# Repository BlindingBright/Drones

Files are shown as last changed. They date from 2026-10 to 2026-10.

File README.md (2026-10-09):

# Drones

Frames, mounts, tunes and flight-log analysis for my FPV builds. Each project lives in its own folder.

## Latest project: Lil Horny (3D whoop)

**[Lil Horny](Lil%20Horny/)** is a 65 mm 3D (reversible-motor) whoop built around a DJI O4 Lite and a
TBS Lucid AIO. It can fly upright and inverted, flipping motor direction mid-air. The folder includes
the printable mounts, the Fusion 360 design, a Betaflight tune and the AM32 ESC configs that go with it,
plus all the blackbox logs and analysis from tuning it.

The frame is based on the **Fractal 65** by Fractal Engineering, and all credit for the frame goes to them.
I tested the prints on a cut-down Fractal 65 and a cut-down Pavo Pico, and they fit both.

### Build list

| Part | Notes |
|---|---|
| Frame | Fractal 65 (or Pavo Pico), cut down |
| Flight controller / ESC | TBS Lucid AIO 1-2S (AM32). The battery mount is shaped to fit around its plugs |
| Video | DJI O4 Lite. The camera mount is made for it |
| Motors | 0802, 16000 kv |
| Props | Gemfan 123D (31 mm) |
| Battery | 2S, 200–300 mAh. Both sizes fit the same battery mount ([example 1](https://www.amazon.com/dp/B0D3F5YF9L), [example 2](https://www.amazon.com/dp/B0GXZCW923)) |

### What's in the folder

```
Lil Horny/
├── Frame Files/          Printable mounts (.obj / .stl), Fusion 360 design (.f3d + script), Lucid AIO .step
│   └── stl/              TPU standoffs (several heights)
├── Tune/
│   ├── Lil Horny 3D Master Tune.txt   Betaflight 4.5.1 CLI "diff all" — the current tune
│   ├── esc1-4_config.bin              AM32 settings for each ESC
│   └── Logs and Analysis/             Blackbox logs, plots, TUNING_NOTES.md, ESC_TEST_PLAN.md
├── README.md              Project info and build list
└── Lil Horny - Lisence Info Please Read.txt
```

### Setting it up

1. **Print the mounts** from `Frame Files/`. The standoffs are meant to be printed in TPU.
2. **ESCs (AM32 2.21):** load the `Tune/esc*_config.bin` files with [esc-configurator.com](https://esc-configurator.com)
   (props off, battery plugged in). The key settings are: bidirectional ON, 12 motor poles, timing 15°,
   startup power 100, min duty 3, motor KV 2200 (stock is fine), complementary PWM ON and running brake 10.
   Updating AM32 can reset these values (it changed timing to 22.5° on mine), so check them again after any flash.
3. **Betaflight 4.5.1:** paste `Tune/Lil Horny 3D Master Tune.txt` into the CLI and it will `save`.
   It turns on 3D mode (1496 low / 1500 neutral / 1504 high, with a deadband of 3), sets
   `motor_poles = 12` and enables bidirectional DShot.
   Before the first flight, check in the Motors tab (props off) that all four motors spin the right way in both directions.

The full pass-by-pass story of the tune — what was changed, why, and what the logs showed — is in
[`Tune/Logs and Analysis/TUNING_NOTES.md`](Lil%20Horny/Tune/Logs%20and%20Analysis/TUNING_NOTES.md).

## How to get the files

**Download everything (easiest):** click the green **Code** button at the top of this page, then **Download ZIP**.

**Clone with git:**

```bash
git clone https://github.com/BlindingBright/Drones.git
```

**Download only the Lil Horny folder** (skips the other projects):

```bash
git clone --filter=blob:none --sparse https://github.com/BlindingBright/Drones.git
cd Drones
git sparse-checkout set "Lil Horny"
```

**Single files:** open the file on GitHub and click the download (↓) button at the top right of the file view.

The project is also updated regularly on
[Google Drive](https://drive.google.com/drive/folders/10FEdRLiF6wVrJK5k8aDCwKiYdItE1z3n?usp=drive_link).

## License

Lil Horny is released under
**[Creative Commons BY-NC-SA 4.0](https://creativecommons.org/licenses/by-nc-sa/4.0/legalcode.en)**.
You're free to print, build, change and share it **for non-commercial use**, as long as you give credit and share
any changes under the same license. See `Lil Horny - Lisence Info Please Read.txt` for the full text.

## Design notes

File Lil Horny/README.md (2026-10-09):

# Lil Horny — Project Info

Lil Horny is released under [CC BY-NC-SA 4.0](https://creativecommons.org/licenses/by-nc-sa/4.0/legalcode.en). Please follow that license.

All project files are in this folder, and the project is updated regularly on
[Google Drive](https://drive.google.com/drive/folders/10FEdRLiF6wVrJK5k8aDCwKiYdItE1z3n?usp=drive_link).

The frame is based on the **Fractal 65**, created by Fractal Engineering; all credit goes to them.
In my testing I used a cut-down Pavo Pico frame and a cut-down Fractal 65. All prints work with both.

## Build List

- **TBS Lucid AIO 1-2S** (the battery mount is made for this and fits around the plugs)
- **DJI O4 Lite** (the camera mount is made for this)
- **Gemfan 123D** propellers
- **0802 16000kv** motors

Fits 200 mAh to 300 mAh 2S packs with the same battery mount:

- <https://www.amazon.com/dp/B0D3F5YF9L>
- <https://www.amazon.com/dp/B0GXZCW923>

## ESC (AM32)

- AM32 updated to 2.21
- 12 pole motor count (important with smaller motors)
- Stock KV (2200) is fine

## Betaflight

- Betaflight 4.5.1 (also set to 12 pole motor count)
- 3D settings: 1504 high, 1496 low, 1500 mid
- 3D deadband in the Receiver tab set to 3

Full CLI settings: [`Tune/Lil Horny 3D Master Tune.txt`](Tune/Lil%20Horny%203D%20Master%20Tune.txt)

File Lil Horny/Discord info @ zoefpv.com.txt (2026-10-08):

Attribution-NonCommercial-ShareAlike 4.0 International
   
CC BY-NC-SA 4.0
Legal Code
Attribution-NonCommercial-ShareAlike 4.0 InternationalExpand
Section 1 – Definitions.
Section 2 – Scope.
Section 3 – License Conditions.
Section 4 – Sui Generis Database Rights.
Section 5 – Disclaimer of Warranties and Limitation of Liability.
Section 6 – Term and Termination.
Section 7 – Other Terms and Conditions.
Section 8 – Interpretation.
Canonical URL https://creativecommons.org/licenses/by-nc-sa/4.0/
Other formats 
Plain Text
RDF/XML
See the deed
Version 4.0 • See the errata page for any corrections and the date of change

 About the license and Creative Commons
Creative Commons Corporation ("Creative Commons") is not a law firm and does not provide legal services or legal advice. Distribution of Creative Commons public licenses does not create a lawyer-client or other relationship. Creative Commons makes its licenses and related information available on an "as-is" basis. Creative Commons gives no warranties regarding its licenses, any material licensed under their terms and conditions, or any related information. Creative Commons disclaims all liability for damages resulting from their use to the fullest extent possible.

Using Creative Commons Public Licenses
Creative Commons public licenses provide a standard set of terms and conditions that creators and other rights holders may use to share original works of authorship and other material subject to copyright and certain other rights specified in the public license below. The following considerations are for informational purposes only, are not exhaustive, and do not form part of our licenses.

Considerations for licensors
Our public licenses are intended for use by those authorized to give the public permission to use material in ways otherwise restricted by copyright and certain other rights. Our licenses are irrevocable. Licensors should read and understand the terms and conditions of the license they choose before applying it. Licensors should also secure all rights necessary before applying our licenses so that the public can reuse the material as expected. Licensors should clearly mark any material not subject to the license. This includes other CC-licensed material, or material used under an exception or limitation to copyright. More considerations for licensors.

Considerations for the public
By using one of our public licenses, a licensor grants the public permission to use the licensed material under specified terms and conditions. If the licensor’s permission is not necessary for any reason–for example, because of any applicable exception or limitation to copyright–then that use is not regulated by the license. Our licenses grant only permissions under copyright and certain other rights that a licensor has authority to grant. Use of the licensed material may still be restricted for other reasons, including because others have copyright or other rights in the material. A licensor may make special requests, such as asking that all changes be marked or described. Although not required by our licenses, you are encouraged to respect those requests where reasonable. More considerations for the public.

Attribution-NonCommercial-ShareAlike 4.0 International
By exercising the Licensed Rights (defined below), You accept and agree to be bound by the terms and conditions of this Creative Commons Attribution-NonCommercial-ShareAlike 4.0 International Public License ("Public License"). To the extent this Public License may be interpreted as a contract, You are granted the Licensed Rights in consideration of Your acceptance of these terms and conditions, and the Licensor grants You such rights in consideration of benefits the Licensor receives from making the Licensed Material available under these terms and conditions.

Section 1 – Definitions.
Adapted Material means material subject to Copyright and Similar Rights that is derived from or based upon the Licensed Material and in which the Licensed Material is translated, altered, arranged, transformed, or otherwise modified in a manner requiring permission under the Copyright and Similar Rights held by the Licensor. For purposes of this Public License, where the Licensed Material is a musical work, performance, or sound recording, Adapted Material is always produced where the Licensed Material is synched in timed relation with a moving image.
Adapter's License means the license You apply to Your Copyright and Similar Rights in Your contributions to Adapted Material in accordance with the terms and conditions of this Public License.
BY-NC-SA Compatible License means a license listed at creativecommons.org/compatiblelicenses, approved by Creative Commons as essentially the equivalent of this Public License.
Copyright and Similar Rights means copyright and/or similar rights closely related to copyright including, without limitation, performance, broadcast, sound recording, and Sui Generis Database Rights, without regard to how the rights are labeled or categorized. For purposes of this Public License, the rights specified in Section 2(b)(1)-(2) are not Copyright and Similar Rights.
Effective Technological Measures means those measures that, in the absence of proper authority, may not be circumvented under laws fulfilling obligations under Article 11 of the WIPO Copyright Treaty adopted on December 20, 1996, and/or similar international agreements.
Exceptions and Limitations means fair use, fair dealing, and/or any other exception or limitation to Copyright and Similar Rights that applies to Your use of the Licensed Material.
License Elements means the license attributes listed in the name of a Creative Commons Public License. The License Elements of this Public License are Attribution, NonCommercial, and ShareAlike.
Licensed Material means the artistic or literary work, database, or other material to which the Licensor applied this Public License.
Licensed Rights means the rights granted to You subject to the terms and conditions of this Public License, which are limited to all Copyright and Similar Rights that apply to Your use of the Licensed Material and that the Licensor has authority to license.
Licensor means the individual(s) or entity(ies) granting rights under this Public License.
NonCommercial means not primarily intended for or directed towards commercial advantage or monetary compensation. For purposes of this Public License, the exchange of the Licensed Material for other material subject to Copyright and Similar Rights by digital file-sharing or similar means is NonCommercial provided there is no payment of monetary compensation in connection with the exchange.
Share means to provide material to the public by any means or process that requires permission under the Licensed Rights, such as reproduction, public display, public performance, distribution, dissemination, communication, or importation, and to make material available to the public including in ways that members of the public may access the material from a place and at a time individually chosen by them.
Sui Generis Database Rights means rights other than copyright resulting from Directive 96/9/EC of the European Parliament and of the Council of 11 March 1996 on the legal protection of databases, as amended and/or succeeded, as well as other essentially equivalent rights anywhere in the world.
You means the individual or entity exercising the Licensed Rights under this Public License. Your has a corresponding meaning.
Section 2 – Scope.
License grant.
Subject to the terms and conditions of this Public License, the Licensor hereby grants You a worldwide, royalty-free, non-sublicensable, non-exclusive, irrevocable license to exercise the Licensed Rights in the Licensed Material to:
reproduce and Share the Licensed Material, in whole or in part, for NonCommercial purposes only; and
produce, reproduce, and Share Adapted Material for NonCommercial purposes only.
Exceptions and Limitations. For the avoidance of doubt, where Exceptions and Limitations apply to Your use, this Public License does not apply, and You do not need to comply with its terms and conditions.
Term. The term of this Public License is specified in Section 6(a).
Media and formats; technical modifications allowed. The Licensor authorizes You to exercise the Licensed Rights in all media and formats whether now known or hereafter created, and to make technical modifications necessary to do so. The Licensor waives and/or agrees not to assert any right or authority to forbid You from making technical modifications necessary to exercise the Licensed Rights, including technical modifications necessary to circumvent Effective Technological Measures. For purposes of this Public License, simply making modifications authorized by this Section 2(a)(4) never produces Adapted Material.
Downstream recipients.
Offer from the Licensor – Licensed Material. Every recipient of the Licensed Material automatically receives an offer from the Licensor to exercise the Licensed Rights under the terms and conditions of this Public License.
Additional offer from the Licensor – Adapted Material. Every recipient of Adapted Material from You automatically receives an offer from the Licensor to exercise the Licensed Rights in the Adapted Material under the conditions of the Adapter’s License You apply.
No downstream restrictions. You may not offer or impose any additional or different terms or conditions on, or apply any Effective Technological Measures to, the Licensed Material if doing so restricts exercise of the Licensed Rights by any recipient of the Licensed Material.
No endorsement. Nothing in this Public License constitutes or may be construed as permission to assert or imply that You are, or that Your use of the Licensed Material is, connected with, or sponsored, endorsed, or granted official status by, the Licensor or others designated to receive attribution as provided in Section 3(a)(1)(A)(i).
Other rights.
Moral rights, such as the right of integrity, are not licensed under this Public License, nor are publicity, privacy, and/or other similar personality rights; however, to the extent possible, the Licensor waives and/or agrees not to assert any such rights held by the Licensor to the limited extent necessary to allow You to exercise the Licensed Rights, but not otherwise.
Patent and trademark rights are not licensed under this Public License.
To the extent possible, the Licensor waives any right to collect royalties from You for the exercise of the Licensed Rights, whether directly or through a collecting society under any voluntary or waivable statutory or compulsory licensing scheme. In all other cases the Licensor expressly reserves any right to collect such royalties, including when the Licensed Material is used other than for NonCommercial purposes.
Section 3 – License Conditions.
Your exercise of the Licensed Rights is expressly made subject to the following conditions.

Attribution.
If You Share the Licensed Material (including in modified form), You must:

retain the following if it is supplied by the Licensor with the Licensed Material:
identification of the creator(s) of the Licensed Material and any others designated to receive attribution, in any reasonable manner requested by the Licensor (including by pseudonym if designated);
a copyright notice;
a notice that refers to this Public License;
a notice that refers to the disclaimer of warranties;
a URI or hyperlink to the Licensed Material to the extent reasonably practicable;
indicate if You modified the Licensed Material and retain an indication of any previous modifications; and
indicate the Licensed Material is licensed under this Public License, and include the text of, or the URI or hyperlink to, this Public License.
You may satisfy the conditions in Section 3(a)(1) in any reasonable manner based on the medium, means, and context in which You Share the Licensed Material. For example, it may be reasonable to satisfy the conditions by providing a URI or hyperlink to a resource that includes the required information.
If requested by the Licensor, You must remove any of the information required by Section 3(a)(1)(A) to the extent reasonably practicable.
ShareAlike.
In addition to the conditions in Section 3(a), if You Share Adapted Material You produce, the following conditions also apply.

The Adapter’s License You apply must be a Creative Commons license with the same License Elements, this version or later, or a BY-NC-SA Compatible License.
You must include the text of, or the URI or hyperlink to, the Adapter's License You apply. You may satisfy this condition in any reasonable manner based on the medium, means, and context in which You Share Adapted Material.
You may not offer or impose any additional or different terms or conditions on, or apply any Effective Technological Measures to, Adapted Material that restrict exercise of the rights granted under the Adapter's License You apply.
Section 4 – Sui Generis Database Rights.
Where the Licensed Rights include Sui Generis Database Rights that apply to Your use of the Licensed Material:

for the avoidance of doubt, Section 2(a)(1) grants You the right to extract, reuse, reproduce, and Share all or a substantial portion of the contents of the database for NonCommercial purposes only;
if You include all or a substantial portion of the database contents in a database in which You have Sui Generis Database Rights, then the database in which You have Sui Generis Database Rights (but not its individual contents) is Adapted Material, including for purposes of Section 3(b); and
You must comply with the conditions in Section 3(a) if You Share all or a substantial portion of the contents of the database.
For the avoidance of doubt, this Section 4 supplements and does not replace Your obligations under this Public License where the Licensed Rights include other Copyright and Similar Rights.

Section 5 – Disclaimer of Warranties and Limitation of Liability.
Unless otherwise separately undertaken by the Licensor, to the extent possible, the Licensor offers the Licensed Material as-is and as-available, and makes no representations or warranties of any kind concerning the Licensed Material, whether express, implied, statutory, or other. This includes, without limitation, warranties of title, merchantability, fitness for a particular purpose, non-infringement, absence of latent or other defects, accuracy, or the presence or absence of errors, whether or not known or discoverable. Where disclaimers of warranties are not allowed in full or in part, this disclaimer may not apply to You.
To the extent possible, in no event will the Licensor be liable to You on any legal theory (including, without limitation, negligence) or otherwise for any direct, special, indirect, incidental, consequential, punitive, exemplary, or other losses, costs, expenses, or damages arising out of this Public License or use of the Licensed Material, even if the Licensor has been advised of the possibility of such losses, costs, expenses, or damages. Where a limitation of liability is not allowed in full or in part, this limitation may not apply to You.
The disclaimer of warranties and limitation of liability provided above shall be interpreted in a manner that, to the extent possible, most closely approximates an absolute disclaimer and waiver of all liability.
Section 6 – Term and Termination.
This Public License applies for the term of the Copyright and Similar Rights licensed here. However, if You fail to comply with this Public License, then Your rights under this Public License terminate automatically.
Where Your right to use the Licensed Material has terminated under Section 6(a), it reinstates:

automatically as of the date the violation is cured, provided it is cured within 30 days of Your discovery of the violation; or
upon express reinstatement by the Licensor.
For the avoidance of doubt, this Section 6(b) does not affect any right the Licensor may have to seek remedies for Your violations of this Public License.

For the avoidance of doubt, the Licensor may also offer the Licensed Material under separate terms or conditions or stop distributing the Licensed Material at any time; however, doing so will not terminate this Public License.
Sections 1, 5, 6, 7, and 8 survive termination of this Public License.
Section 7 – Other Terms and Conditions.
The Licensor shall not be bound by any additional or different terms or conditions communicated by You unless expressly agreed.
Any arrangements, understandings, or agreements regarding the Licensed Material not stated herein are separate from and independent of the terms and conditions of this Public License.
Section 8 – Interpretation.
For the avoidance of doubt, this Public License does not, and shall not be interpreted to, reduce, limit, restrict, or impose conditions on any use of the Licensed Material that could lawfully be made without permission under this Public License.
To the extent possible, if any provision of this Public License is deemed unenforceable, it shall be automatically reformed to the minimum extent necessary to make it enforceable. If the provision cannot be reformed, it shall be severed from this Public License without affecting the enforceability of the remaining terms and conditions.
No term or condition of this Public License will be waived and no failure to comply consented to unless expressly agreed to by the Licensor.
Nothing in this Public License constitutes or may be interpreted as a limitation upon, or waiver of, any privileges and immunities that apply to the Licensor or You, including from the legal processes of any jurisdiction or authority.

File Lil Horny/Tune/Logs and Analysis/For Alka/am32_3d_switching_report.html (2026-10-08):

AM32 2.21 · 3D direction-switch test · Oct 2026

# Lucid AIO 3D Switching Tests

Min duty and KV slider tests on a 3D whoop, following your suggested plan: default, then min duty 3, then KV halved, then min duty 4 with KV ~2200 (flown at 2100). Plus the earlier logs comparing factory firmware, 22.5° timing and startup power 120.

Craft TBS Lucid AIO (AT32F435 FC + AM32 ESC) · 0802 16000kv, 12-pole · Gemfan 31mm prototype 3D props · 2S 300mAh · DJI O4 Lite · ~30 g
Betaflight 4.5.1 · 8k/8k · feature 3D · DShot600 bidir · dshot_idle_value 400 (4%) · thrust_linear 20 · blackbox 2 kHz
AM32 constant bidirectional, comp PWM, variable PWM, stuck rotor ON · sine startup OFF · timing 15° · startup 100 · poles 12 · running brake 10

## Summary

- Min duty 4 + KV 2100 is the clear winner: median switch 153 → 126 ms (−18%), now faster than factory 2.03 (136 ms). All four motors land within 5 ms of each other (125–130 ms).
- It's also the smoothest: low-rpm eRPM ripple halved (3.3k → 1.7k), motor spread 70 → 38 ms, slow switches 33% → 7%.
- The rough 30–60k eRPM window finally moved: with min duty 3 / KV 5100 it sat at ~40–110 ms after every switch. With min duty 4 / KV 2100 the motor dips to ~20k at ~60 ms and is climbing by ~85 ms.
- Min duty 3 alone smoothed things; KV 5100 alone added speed but brought ripple back; the low KV + min duty 4 combination got both.
- Final: min duty back to 3 at KV 2100 (E) switches exactly as fast as D (126 ms median), a bit more consistently (p90 148 ms, spread 34 ms), with less pitch overshoot. This is the setting we're keeping.

## Min duty / KV test (A → E)

Same Betaflight config for every run; B–D on the same day with the same props. Times are from the moment Betaflight flips direction until each motor reaches 100k eRPM in the new direction; medians over clean reversals (no second flip within 450 ms). Impacts trimmed out.

Config | Reversals | Switch median | Switch p90 | Restart phase (min → 100k) | Slow >200 ms | Motor spread | Low-rpm ripple | Attitude kick med / p90
A · default (min duty 0.5, KV 10220) | 52 | 153 ms | 183 ms | 45 ms | 17 (33%) | 70 ms | 3.3k | 60 / 136 °/s
B · min duty 3 | 23 | 147 ms | 172 ms | 42 ms | 1 (4%) | 49 ms | 1.8k | 85 / 173 °/s
C · min duty 3 + KV 5100 | 28 | 142 ms | 172 ms | 39 ms | 1 (4%) | 45 ms | 3.5k | 68 / 172 °/s
D · min duty 4 + KV 2100 | 30 | 126 ms | 154 ms | 37 ms | 2 (7%) | 38 ms | 1.7k | 82 / 149 °/s
E · min duty 3 + KV 2100 (kept) | 28 | 126 ms | 148 ms | 36 ms | 1 (4%) | 34 ms | 1.8k | 84 / 185 °/s

Per-motor median switch (BF m0 / m1 / m2 / m3) | m0 | m1 | m2 | m3
A · default | 152 | 147 | 156 | 155
B · min duty 3 | 143 | 149 | 146 | 154
C · min duty 3 + KV 5100 | 139 | 135 | 139 | 149
D · min duty 4 + KV 2100 | 125 | 128 | 126 | 130
E · min duty 3 + KV 2100 | 118 | 128 | 123 | 129

Low-rpm ripple = RMS of 20–200 Hz eRPM ripple while a motor runs between 5k and 150k eRPM, away from reversals. A pools two days of default flying (3 packs). Attitude kick = peak roll/pitch tracking error in the 300 ms after a switch.

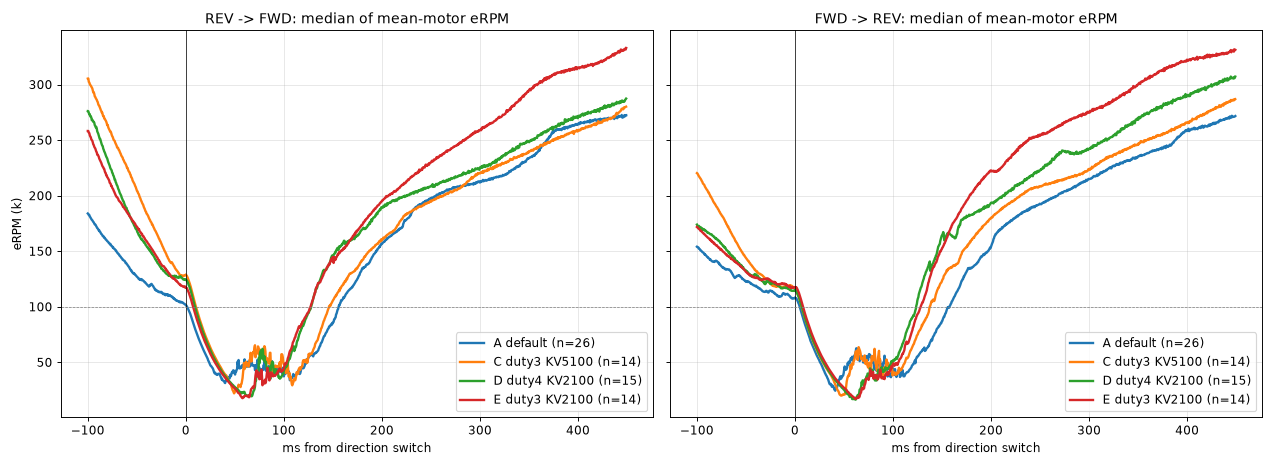
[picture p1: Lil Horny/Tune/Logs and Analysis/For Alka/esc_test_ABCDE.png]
Median mean-motor eRPM through reversals for configs A, C, D and E, both directions


Median eRPM (mean of 4 motors) aligned on the direction switch. A and C sit in a noisy 30–60k section from ~40–110 ms. Both KV 2100 runs (D green, E red) dip cleaner to ~20k around 60 ms and reach 100k ~15–20 ms ahead of C in both directions. D and E overlap through the switch itself. B is left off for readability.

## Earlier logs: firmware and other settings

Log | Reversals | Switch median | Switch p90 | Stop phase | Motor spread
Factory AM32 (2.03), timing 15° | 24 | 136 ms | 169 ms | 68 ms | 37 ms
2.21, timing 22.5° (reset by the update) | 10 | 140 ms | 168 ms | 88 ms | 49 ms
2.21, timing 15° | 20 | 146 ms | 175 ms | 91 ms | 37 ms
2.21, startup power 120 | 11 | 144 ms | 162 ms | 98 ms | 56 ms
2.21, startup power 100 (default) | 16 | 148 ms | 177 ms | 97 ms | 62 ms

Stop phase = switch → eRPM minimum. On 2.21 the stop phase is ~30 ms longer than on factory firmware; the restart phase is actually a little shorter on 2.21. Factory log caveats: Betaflight idle was 2.8% and the Betaflight tune was untuned (first flight).

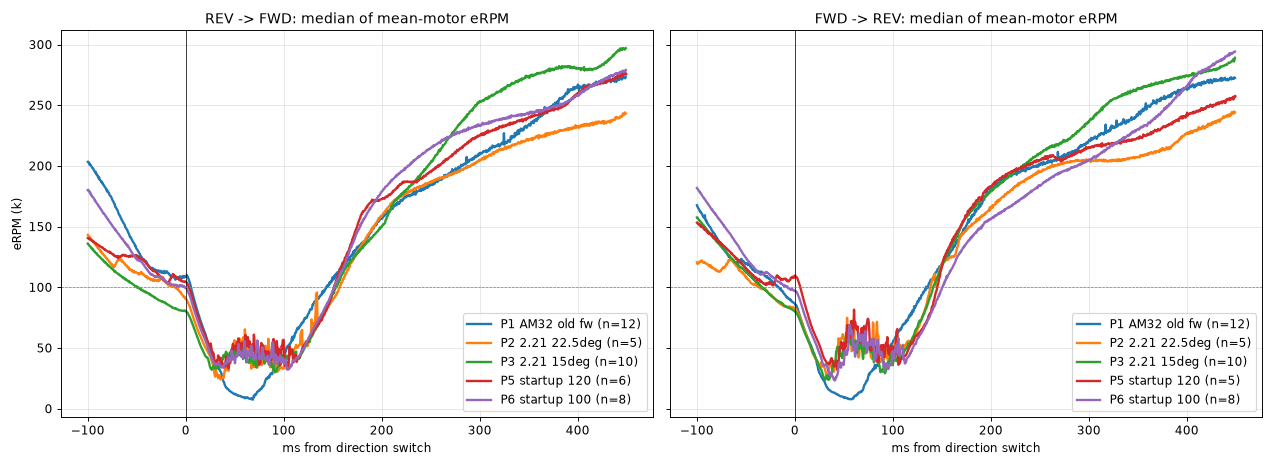
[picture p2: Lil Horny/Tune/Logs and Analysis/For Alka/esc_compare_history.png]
Median mean-motor eRPM through reversals for factory firmware and several 2.21 settings


Factory 2.03 (blue) falls through to ~10k eRPM at ~60 ms and climbs straight out. Every 2.21 setting sits in the rough 30–60k section first.

## Other observations

Min duty adds on top of the Betaflight idle. At the same dshot_idle_value (4%), idle speed rose from roughly 70–79k (A) to 87–93k (B) and 85–101k (D) eRPM. Center stick floats a bit more as a result.

KV 5100 alone cost smoothness; KV 2100 + min duty 4 didn't. C's ripple went back to default levels, D's is the lowest of any run.

Flight side effect in D: pitch overshoot rose a little (step peak 1.22 → 1.37). Back at min duty 3 (E) it returned to 1.22, and inverted motor jitter dropped (19 → 17).

D vs E is close enough that the pilot couldn't pick one by feel; the logs agree. Same switch speed and smoothness, E slightly more consistent.

No desyncs or failed restarts in A–E.

Failed restart · 2.21 at 22.5° timing

### Motor never restarted after a reversal

Right after the AM32 update (which silently changed timing 15° → 22.5°), BF motor 0 (ESC M1) went to 0 eRPM after a REV → FWD switch at ~37.1 s and stayed there for 0.75 s while Betaflight commanded 2047, then the quad crashed. Stuck rotor protection was ON. The other three motors restarted normally. No repeat since going back to 15°.

File 02, log 4 of 5.

## Questions

1. The 30–60k eRPM section shrank only at KV 2100. Is that the low-rpm throttle limit releasing, and is there more to get by going lower than 2100 or higher on min duty, or does desync risk climb fast from here?
2. What changed in 3D reversal handling between 2.03 and 2.21? Factory firmware stopped the motor ~30 ms faster at default settings.
3. Worth trying lower startup power with min duty 4 for smoothness, or leave startup at 100?
4. You mentioned a possible 3D fix for desyncs. Would the failed restart above be relevant?

## Log files

File | What to look at
01_AM32-factory-2.03_… | Factory reference. AM32 still had poles set to 14.
02_AM32-2.21_timing22.5-…_STALL-in-log4 | 5 logs. Log 4 = failed restart at ~37.1 s. Log 1 end = prop came off (not ESC). Log 5 = clean flight.
03_…_startup120_… | Tree hit at 55.8 s.
04_…_DEFAULT-A1 | Log 4 is the flight (106 s, clean).
05_…_DEFAULT-A2 | 2 packs. Impact at 70.0 s in log 1; log 2 truncated (flash full).
06_…_minduty3_kv10220_TEST-B | Log 3 is the flight; impact at 79 s.
07_…_minduty3_kv5100_TEST-C | Crash at 88.6 s.
08_…_minduty4_kv2100_TEST-D | Clean 86 s flight, no impacts.
09_…_minduty3_kv2100_TEST-E | Clean 94 s flight, no impacts. Final setting.

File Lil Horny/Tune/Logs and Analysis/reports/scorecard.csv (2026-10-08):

label | duration_s | motor_poles | reversals | rev_spinup_ms_med | rev_motor_spread_ms_med | rev_peak_err_med | rev_peak_err_p90 | steady_err_rms_roll | steady_err_rms_pitch | steady_err_rms_yaw | gyro_unfilt_400_1000_db_roll | gyro_filt_80_400_db_roll | dterm_rms_roll | dterm_rms_pitch | step_peak_roll | step_settle_roll | step_peak_pitch | step_settle_pitch | step_peak_yaw | step_settle_yaw
Pass 1 baseline | 86.2 | 14 | 24 | 110.9 | 51.5 | 48.0 | 106.0 | 14.9 | 13.9 | 9.2 | -5.8 | -16.9 | 20.4 | 15.7 | 1.14 | 0.88 | 1.34 | 1.0 | 0.91 | 0.82
Pass 2 log5 (good flight) | 54.2 | 12 | 10 | 113.6 | 77.1 | 72.0 | 291.0 | 9.0 | 6.3 | 2.9 | -4.7 | -18.2 | 16.3 | 13.7 | 1.13 | 0.88 | 1.38 | 0.91 | 0.97 | 0.87
Pass 3 | 93.8 | 12 | 20 | 115.2 | 51.8 | 54.0 | 135.0 | 7.7 | 6.6 | 3.0 | -4.4 | -22.3 | 14.5 | 11.3 | 1.08 | 0.87 | 1.22 | 0.95 | 0.86 | 0.78
Pass 4 (crash trimmed) | 47.6 | 12 | 9 | 112.0 | 46.7 | 70.0 | 129.0 | 7.7 | 5.5 | 2.8 | -5.2 | -17.3 | 22.2 | 17.4 | 1.12 | 0.93 | 1.55 | 1.09 | 0.85 | 0.78
Pass 5 (tree trimmed) | 55.5 | 12 | 12 | 121.6 | 70.0 | 71.0 | 337.0 | 6.3 | 6.5 | 2.6 | -4.7 | -14.5 | 19.3 | 17.4 | 1.03 | 0.88 | 1.35 | 0.92 | 0.92 | 0.83
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

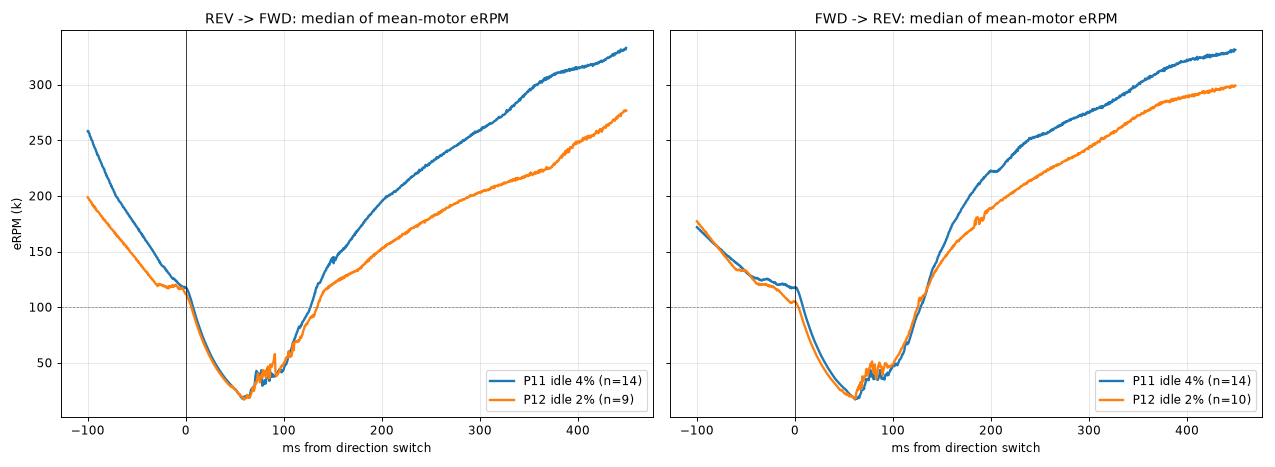
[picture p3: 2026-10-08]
Lil Horny/Tune/Logs and Analysis/reports/esc_idle_E_vs_12.png

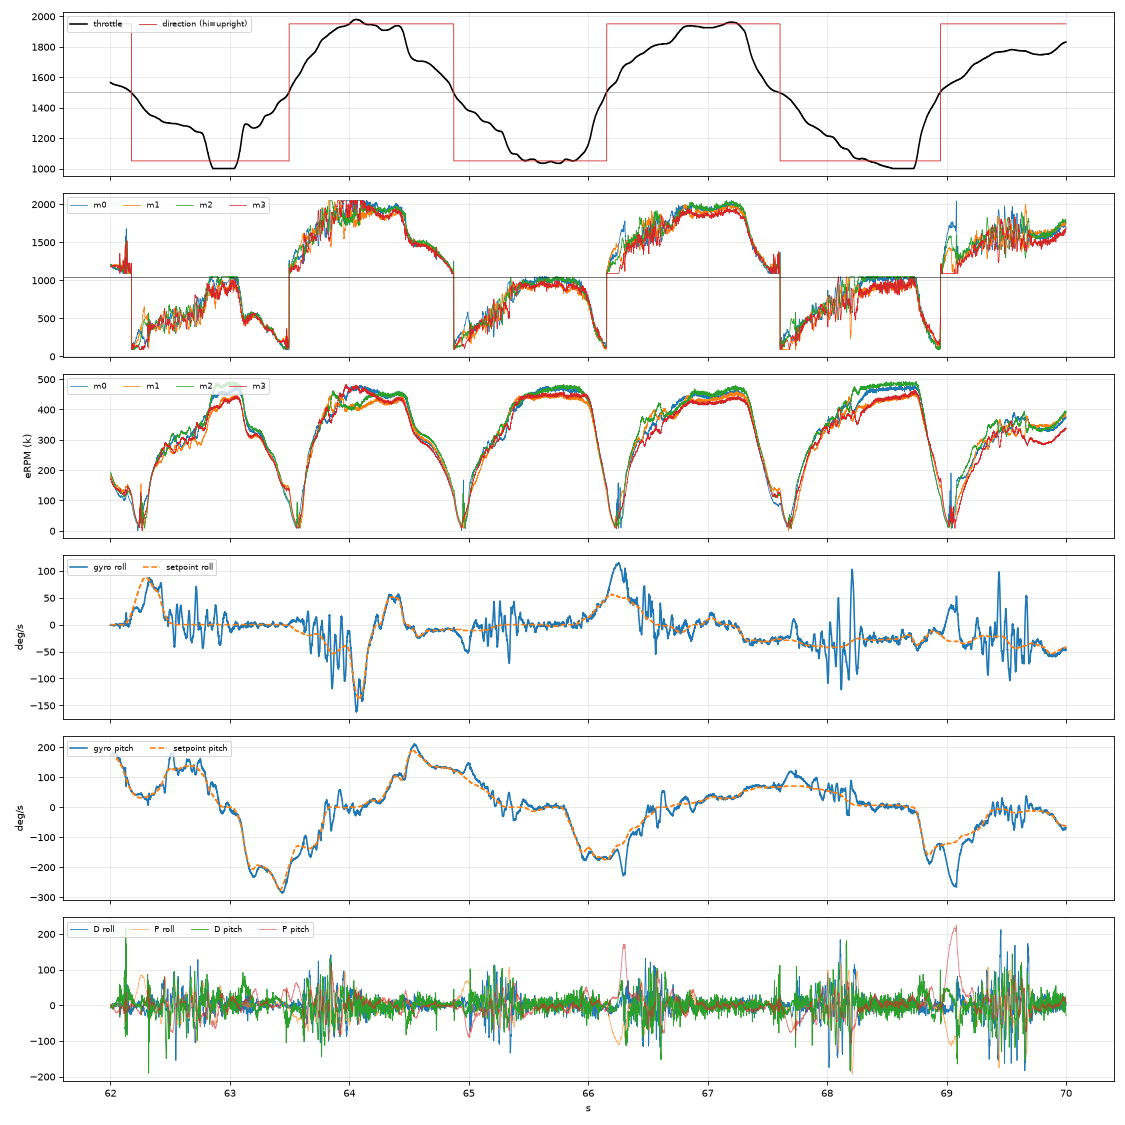
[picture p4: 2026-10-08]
Lil Horny/Tune/Logs and Analysis/reports/Pass_11_ticktock.png

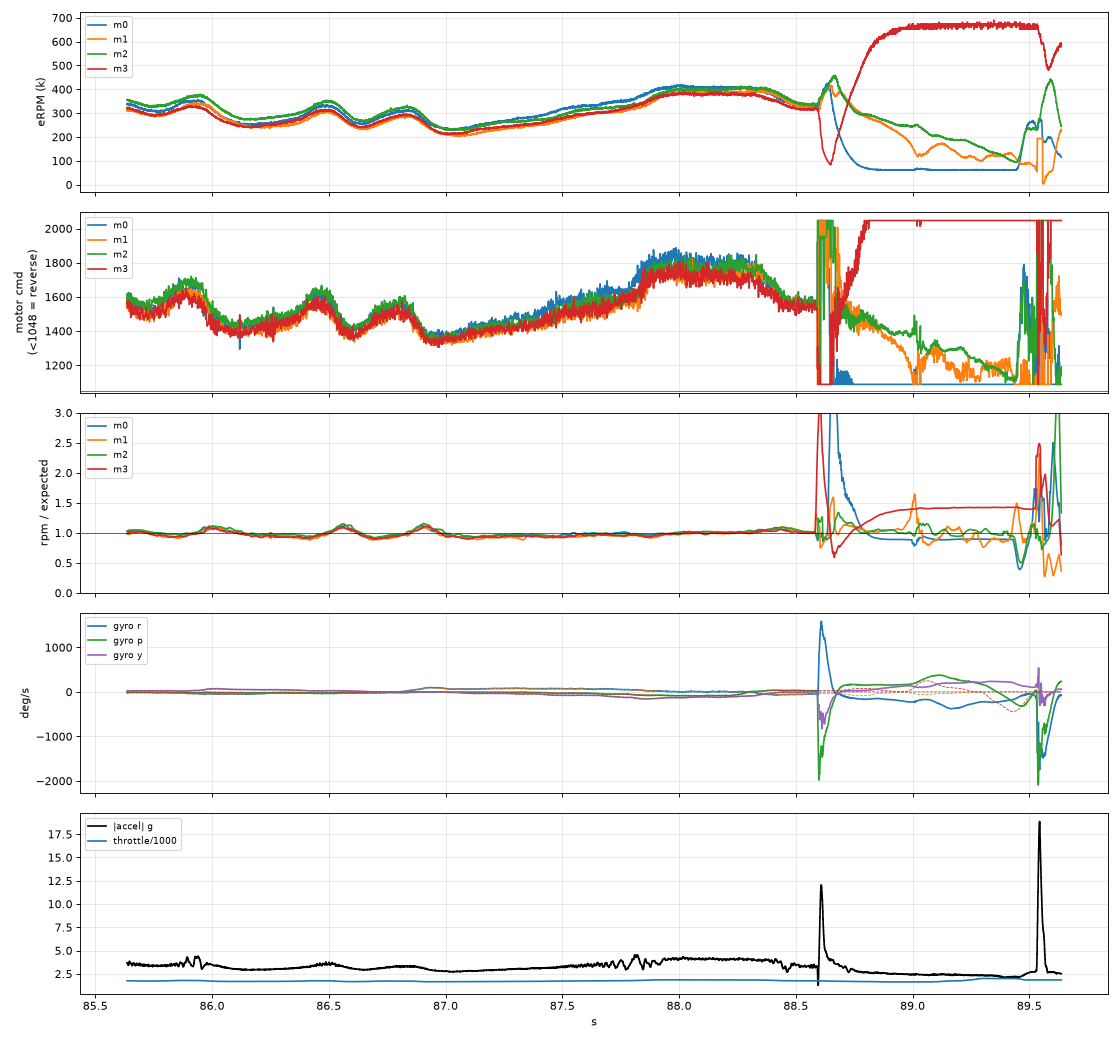
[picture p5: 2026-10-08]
Lil Horny/Tune/Logs and Analysis/reports/Pass_9_crash.png

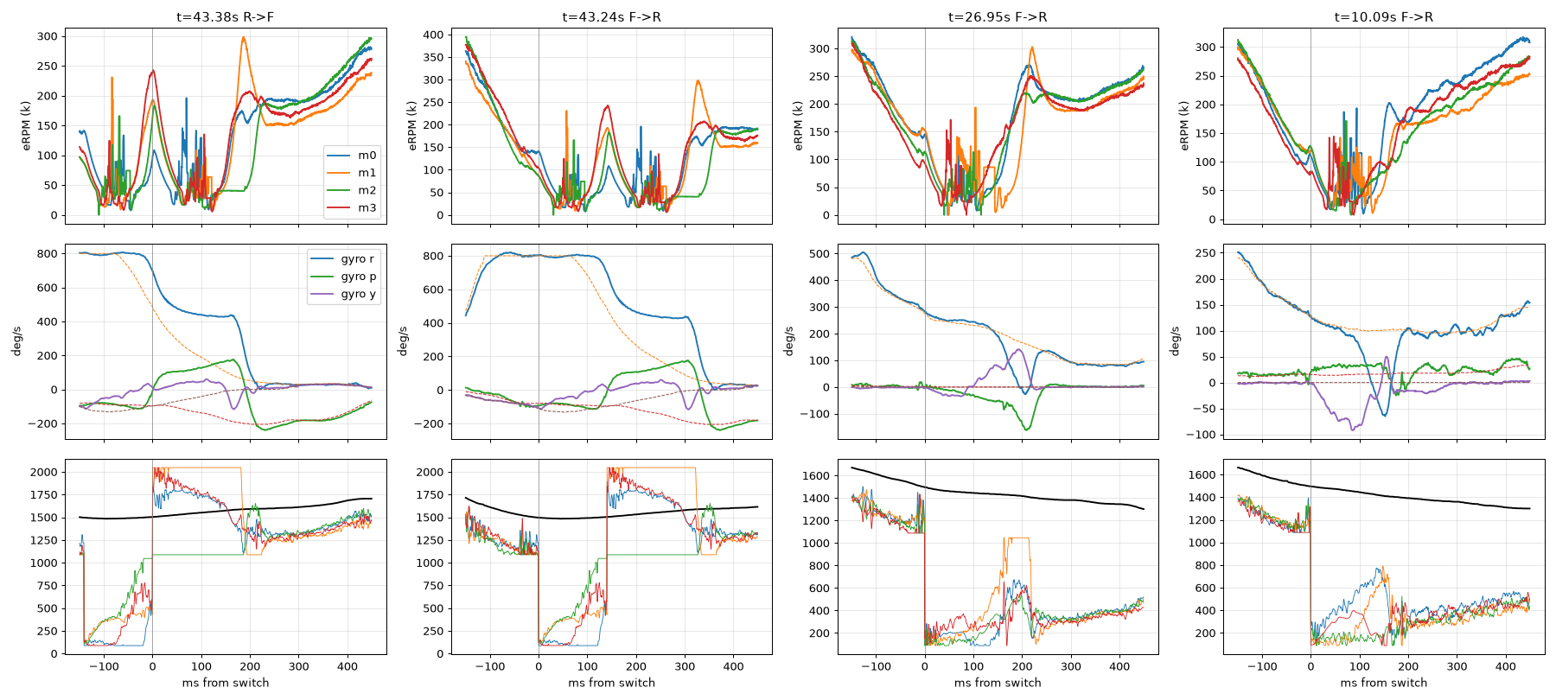
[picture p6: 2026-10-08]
Lil Horny/Tune/Logs and Analysis/reports/Pass_5__tree_trimmed__worst_reversals.png

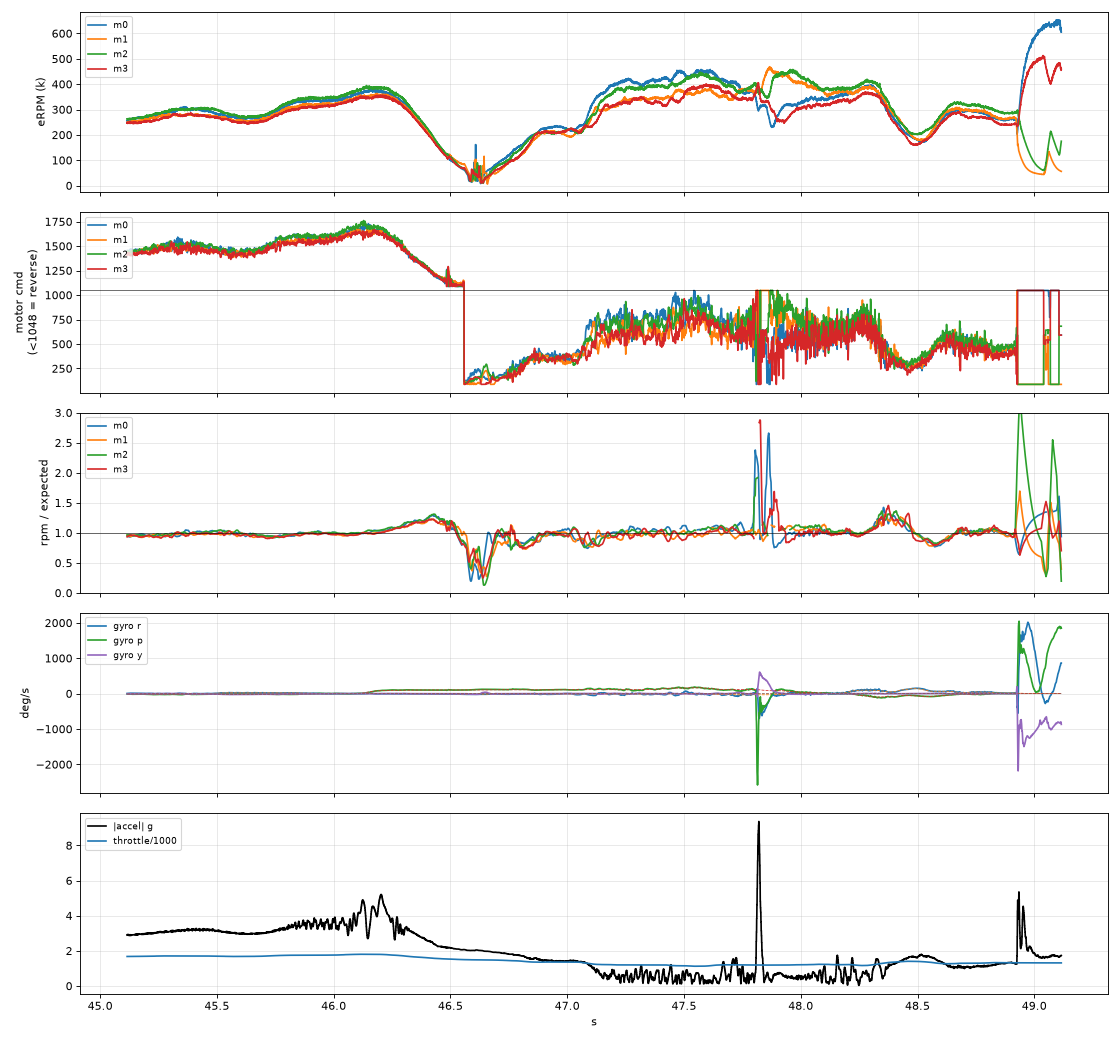
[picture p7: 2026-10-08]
Lil Horny/Tune/Logs and Analysis/reports/Pass_4_crash.png

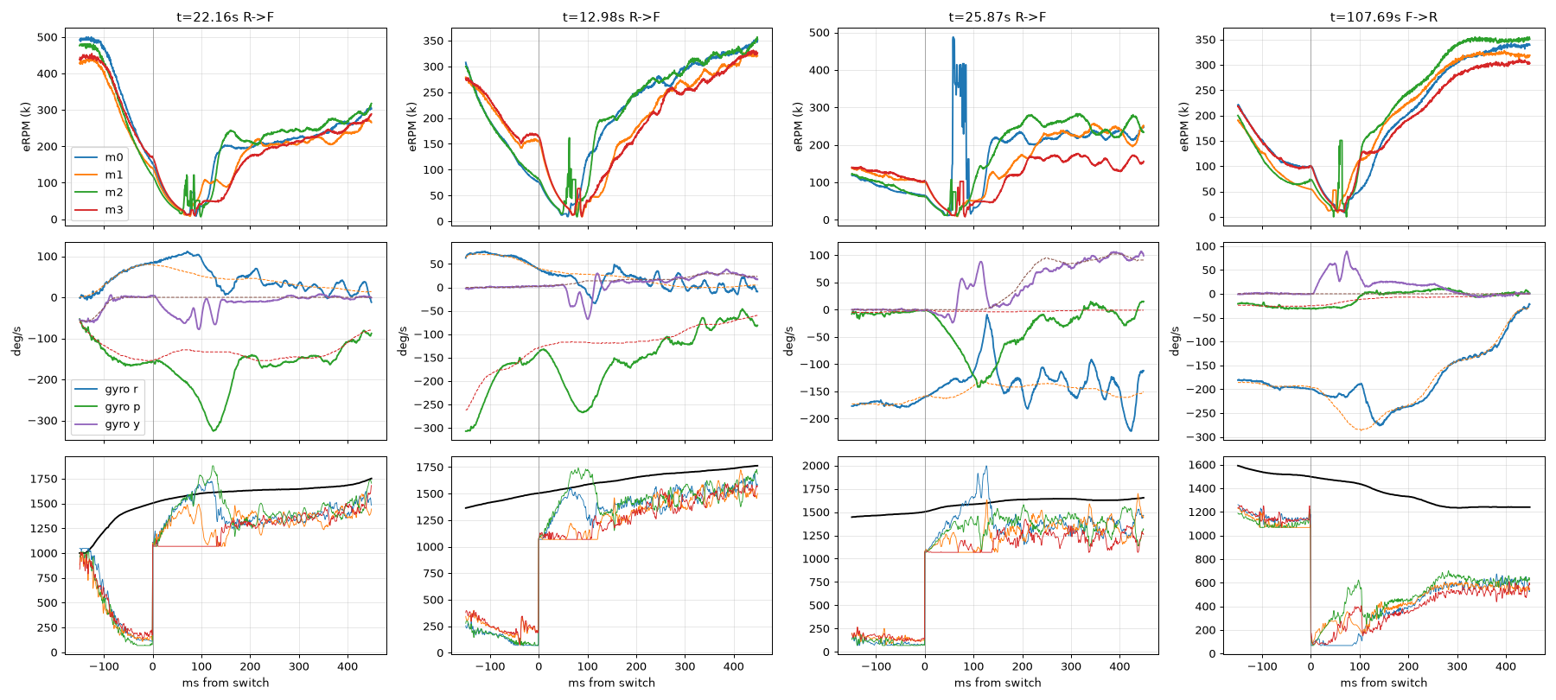
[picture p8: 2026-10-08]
Lil Horny/Tune/Logs and Analysis/reports/Pass_14_worst_reversals.png

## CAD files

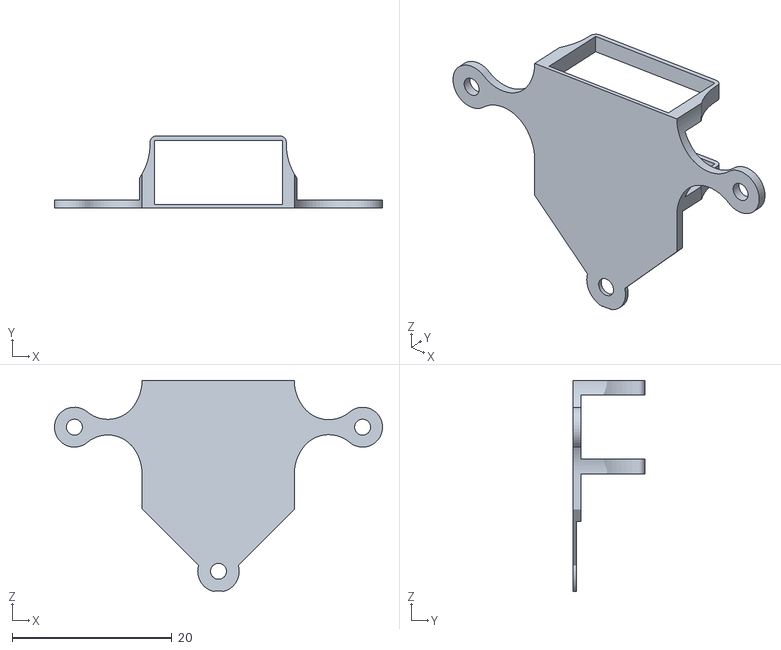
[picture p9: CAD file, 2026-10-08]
Lil Horny/Frame Files/Battery Mount.obj
41.0 x 9.00 x 26.4

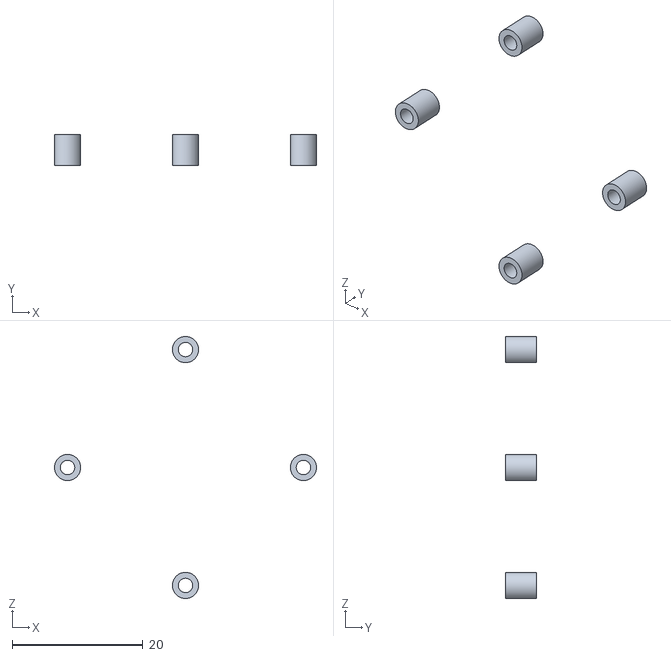
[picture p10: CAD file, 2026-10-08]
Lil Horny/Frame Files/stl/standoffs_TOP_O4-to-Lucid_4.7mm_x4.stl
40.1 x 4.70 x 40.1

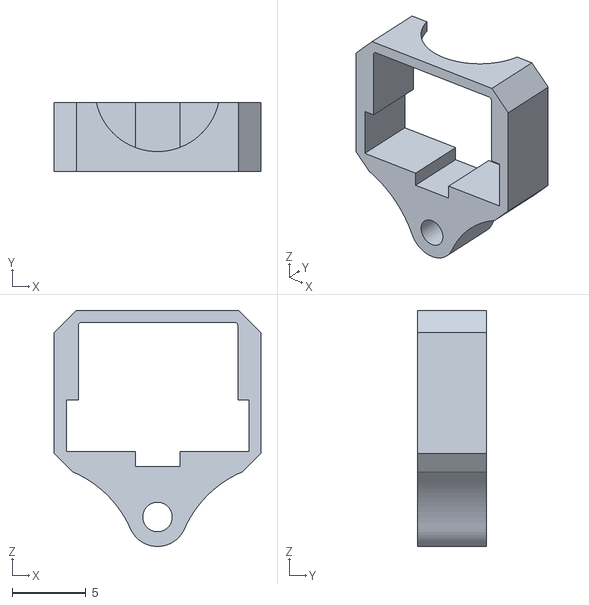
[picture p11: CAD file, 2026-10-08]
Lil Horny/Frame Files/Camera Mount.obj
14.0 x 4.70 x 16.0

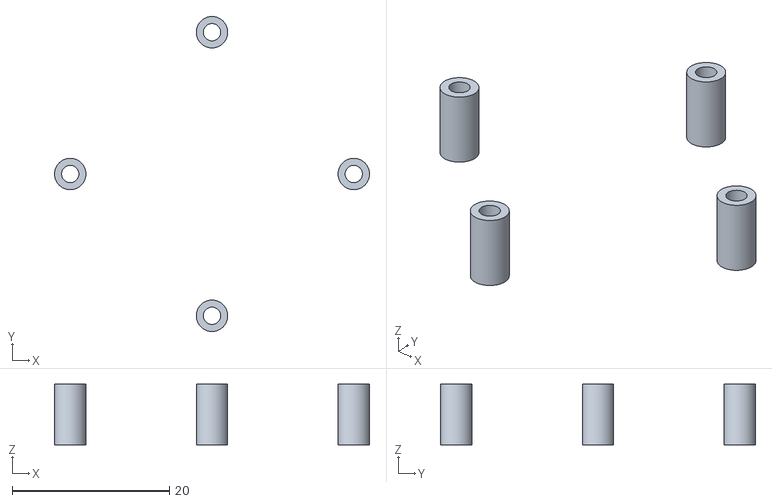
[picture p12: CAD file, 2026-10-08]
Lil Horny/Frame Files/stl/standoffs_TOP_O4-to-Lucid_7.7mm_x4.stl
40.1 x 40.1 x 7.70

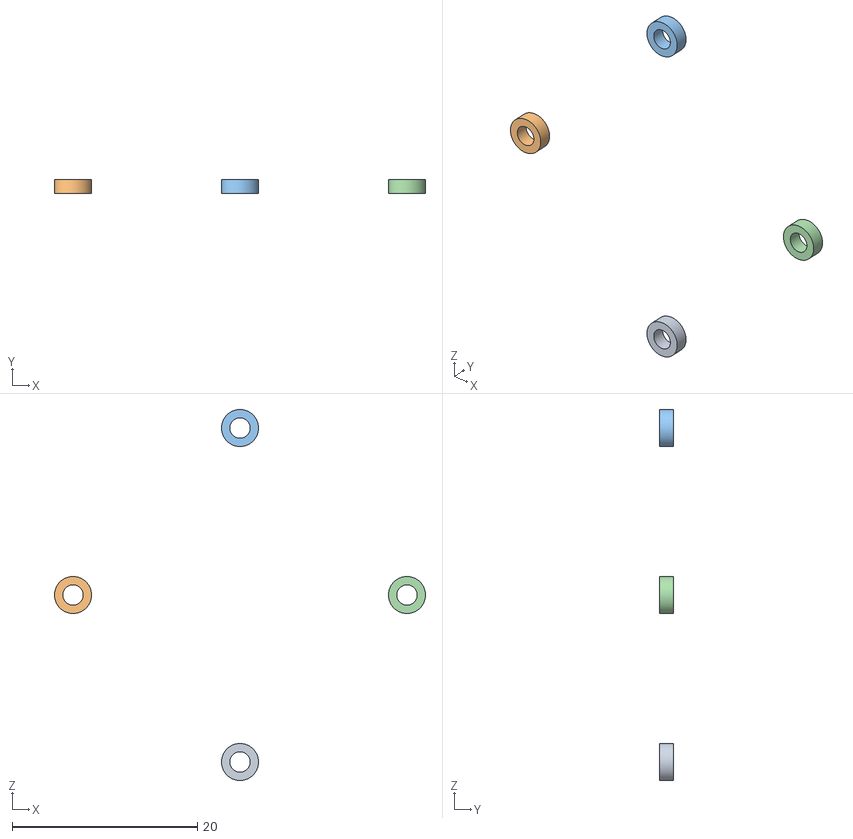
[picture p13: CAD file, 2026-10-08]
Lil Horny/Frame Files/Standoffs BOTTOM plate-O4 1.5mm x4 (TPU).obj
40.1 x 1.50 x 40.1
Standoff 1
Standoff 2
Standoff 3
Standoff 4

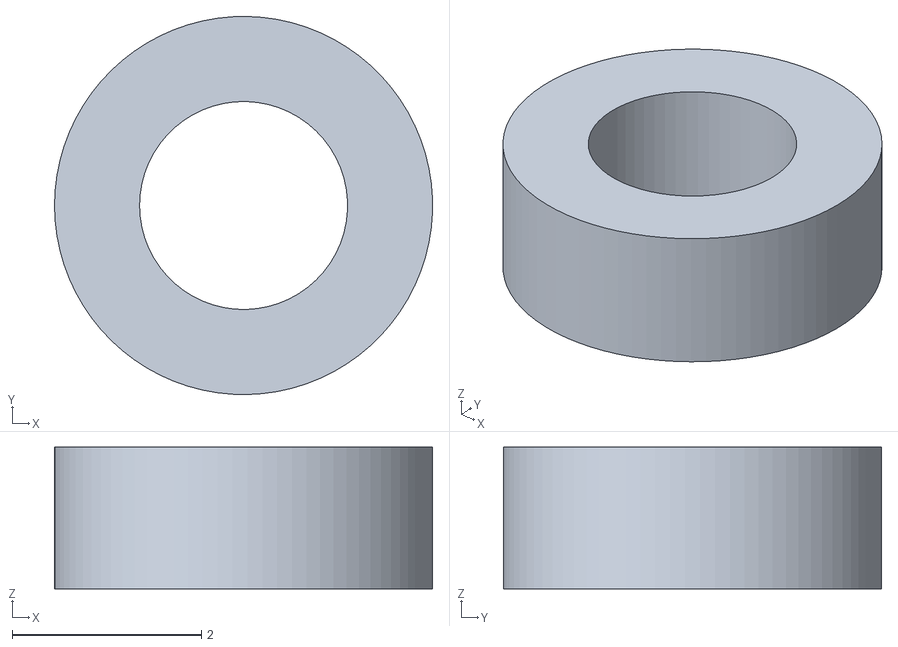
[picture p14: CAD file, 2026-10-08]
Lil Horny/Frame Files/stl/standoff_lower_plate-to-O4_1.5mm_x4.stl
4.00 x 4.00 x 1.50

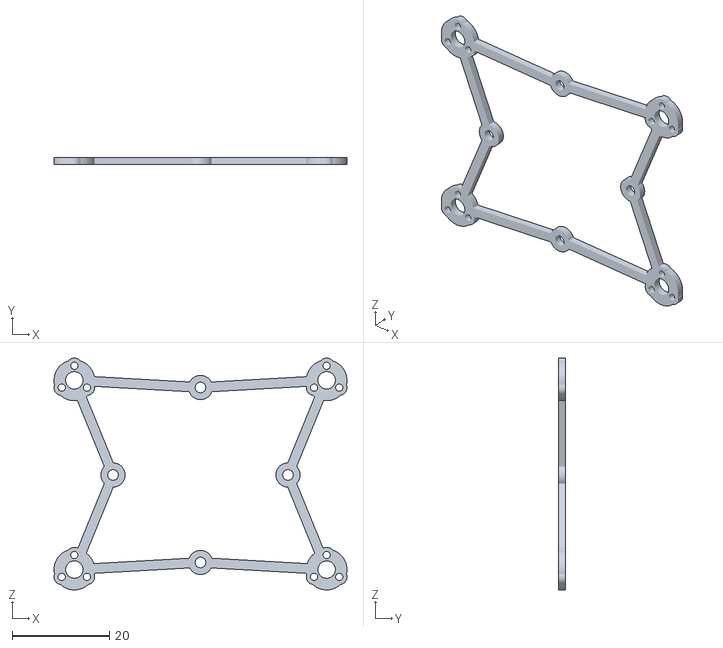
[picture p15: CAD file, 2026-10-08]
Lil Horny/Frame Files/Frame - Fractal 65 Lite (streamlined).obj
60.4 x 1.50 x 47.8

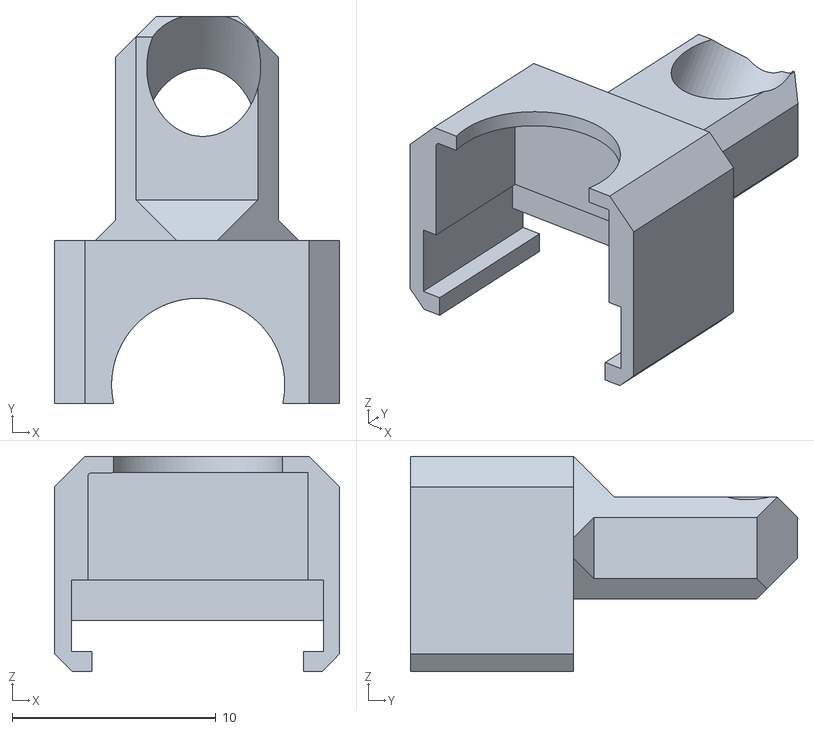
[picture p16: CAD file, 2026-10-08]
Lil Horny/Frame Files/Antenna Mount.obj
14.0 x 19.0 x 10.6

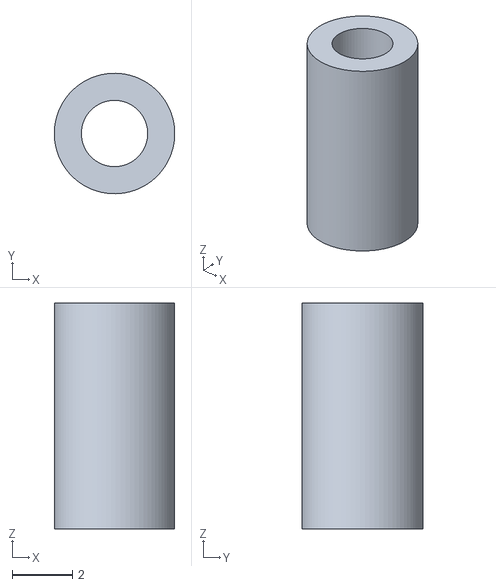
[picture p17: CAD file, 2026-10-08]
Lil Horny/Frame Files/stl/standoff_upper_O4-to-Lucid_7.5mm_x4.stl
4.00 x 4.00 x 7.50

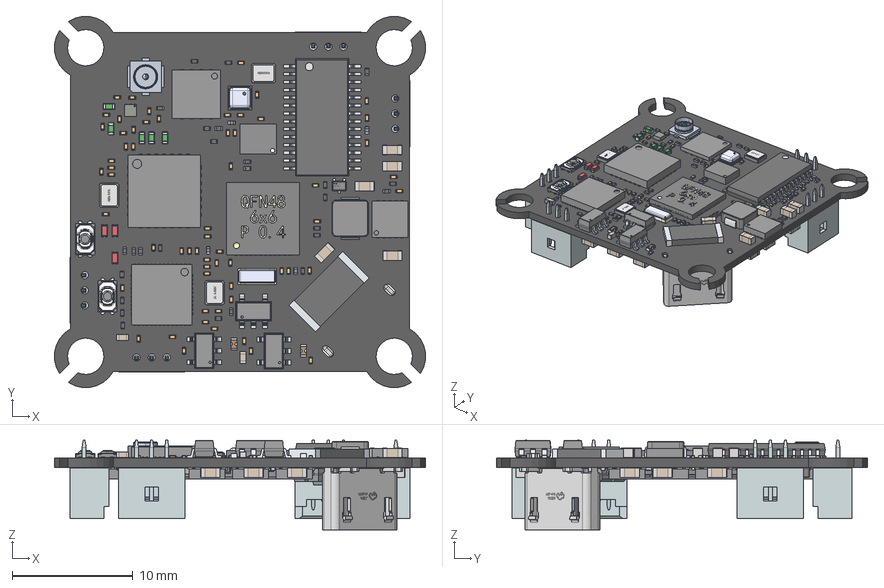
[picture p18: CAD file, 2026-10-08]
Lil Horny/Frame Files/TBS_Lucid_AIO_1-2S.step
30.7 x 30.7 x 7.44 mm
0402SMD CAPACITOR x 18
User Library-DIODE_SOD-923 x 12
User Library-SOD882-1 x 12
0603SMD CAPACITOR x 17
r0201v5 x 112
MCRF
User Library-SKY13351-378LF
C0201_020 (1) x 267
NFM15PC105R0G3D x 2
QFN 48 6x6 pitch 0_4
ABM11W-32.0000MHZ-8-B1U-T3--3DModel-STEP-400430 x 3
CSTCE
ThermalPin x 4
PinsArrayLR x 4
PinsArrayTB x 2
PinsArrayL x 6
PinsArrayR x 6
User Library-TSSOP-28__X2_041A043E0440043F04430441_X0_
User Library-TSSOP-28__X2_041C04350442043A0430_X0_
User Library-TSSOP-28__X2_041D043E0436043A0430_X0_ x 14
BMI270--3DModel-STEP-56544
BMP388--3DModel-STEP-56544
Free-Models x 4
Free-Models016 x 4
Free-Models026 x 4
Free-Models027 x 4
Free-Models028 x 4
Free-Models009 x 4
Free-Models008 x 4
Free-Models007 x 4
Free-Models022 x 4
Free-Models023 x 4
Free-Models001 x 4
Free-Models003 x 4
Free-Models002 x 4
Free-Models024 x 4
Free-Models025 x 4
Free-Models014 x 4
Free-Models013 x 4
Free-Models015 x 4
Free-Models017 x 4
Free-Models018 x 4
Free-Models020 x 4
Free-Models021 x 4
Free-Models019 x 4
Free-Models005 x 4
Free-Models004 x 4
Free-Models006 x 4
Free-Models012 x 4
Free-Models011 x 4
Free-Models010 x 4
pins x 2
button x 2
accents x 2
logo x 2
term1
term2
Pins x 12
Pin1 x 5
Pin2 x 5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

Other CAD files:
Lil Horny/Frame Files/stl/standoffs_BOTTOM_plate-to-O4_1.5mm_x4.stl
Lil Horny/Frame Files/Standoffs TOP O4-Lucid 4.7mm x4 (TPU).obj
Lil Horny/Frame Files/Lil Horny.f3d

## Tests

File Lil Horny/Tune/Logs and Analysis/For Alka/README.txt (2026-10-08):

3D whoop: TBS Lucid AIO (AT32F435 FC + AM32), 0802 16000kv (12-pole), Gemfan 31mm prototype 3D props,
2S 300mAh, DJI O4 Lite, ~30 g. Betaflight 4.5.1, 8k/8k, feature 3D, DShot600 bidirectional, 2 kHz blackbox.

AM32 settings common to all 2.21 logs: bidirectional ON, complementary PWM ON, variable PWM ON,
stuck rotor protection ON, sine startup OFF, stall protection OFF, brake on stop OFF, auto-timing OFF,
poles 12, running brake 10, stopped brake 10, sine range 15, sine power 6.
Only the values in each filename change.

Betaflight: tune evolved during 01-03. 04-07 all use the SAME Betaflight config
(dshot_idle_value 400 = 4%, thrust_linear 20), so 04-07 are a clean ESC-only comparison.

File  | Use                         | Notes
------+-----------------------------+--------------------------------------------------------------
01    | factory firmware reference  | AM32 still set to 14 poles, BF idle 2.8%. Cleanest reversals in eRPM.
02    | timing 22.5 (reset by 2.21) | 5 logs. Log 4: motor 1 (BF m0) stops at 0 rpm right after a
      |                             | reversal at ~37.1 s and never restarts, while commanded 2047 for 0.75 s, then crash.
      |                             | Log 1 end = prop came off (not ESC). Log 5 is the good flight.
03    | startup power 120           | Tree hit at 55.8 s; analyze 0-55.5 s.
04    | DEFAULT (A1)                | Log 4 is the flight (106 s, clean).
05    | DEFAULT (A2)                | 2 packs. Log 1 impact at 70.0 s; log 2 truncated (flash full).
06    | TEST B: min duty 3          | Log 3 is the flight; impact at 79 s.
07    | TEST C: min duty 3, KV 5100 | Crash at 88.6 s; analyze 0-88.4 s.
08    | TEST D: min duty 4, KV 2100 | Clean 86 s flight, no impacts. 126 ms median.
09    | TEST E: min duty 3, KV 2100 | Clean 94 s flight, no impacts. 126 ms median, most consistent. FINAL SETTING.

Plots: esc_test_ABCDE.png (A, C, D, E), esc_test_ABCD.png (A vs B vs C vs D), esc_test_ABC.png, esc_compare_history.png (all firmware/settings).
Switch time = from BF direction switch until eRPM >= 100k in the new direction (per motor, median).

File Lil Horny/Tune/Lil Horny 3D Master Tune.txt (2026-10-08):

# 
# diff all

# version
# Betaflight / AT32F435M (A435) 4.5.1 Dec  4 2024 / 09:48:50 (77d01ba3b) MSP API: 1.46
# config rev: 283a21f

# start the command batch
batch start

# reset configuration to default settings
defaults nosave

board_name TBS_LUCID_AIO
manufacturer_id TEBS
mcu_id 60b47d505c3300000dc0071b
signature 

# resources
resource MOTOR 1 A09
resource MOTOR 2 A08
resource MOTOR 3 A03
resource MOTOR 4 A10

# feature
feature 3D

# serial
serial 0 64 115200 57600 0 115200
serial 2 131073 115200 57600 0 115200
serial 4 0 115200 57600 0 115200

# aux
aux 0 0 0 1675 2100 0 0
aux 1 29 1 900 1700 0 0

# master
set dyn_notch_count = 1
set dyn_notch_q = 500
set gyro_lpf1_dyn_min_hz = 300
set gyro_lpf1_dyn_max_hz = 600
set acc_calibration = -9,81,-4149,1
set baro_hardware = NONE
set dshot_idle_value = 200
set dshot_bidir = ON
set motor_poles = 12
set align_board_pitch = 180
set align_board_yaw = 45
set yaw_motors_reversed = ON
set 3d_deadband_low = 1496
set 3d_deadband_high = 1504
set 3d_neutral = 1500
set 3d_deadband_throttle = 3
set deadband = 3
set yaw_deadband = 3
set simplified_gyro_filter = OFF

profile 0

# profile 0
set dterm_lpf1_dyn_min_hz = 90
set dterm_lpf1_dyn_max_hz = 180
set dterm_lpf2_static_hz = 180
set p_pitch = 44
set f_pitch = 100
set i_roll = 88
set d_roll = 44
set f_roll = 110
set p_yaw = 50
set i_yaw = 95
set d_min_roll = 38
set d_min_pitch = 42
set thrust_linear = 10
set simplified_pids_mode = OFF
set simplified_dterm_filter = OFF
set tpa_rate = 45
set tpa_breakpoint = 1450

profile 1

profile 2

profile 3

# restore original profile selection
profile 0

rateprofile 0

# rateprofile 0
set rateprofile_name = Z' Magic
set thr_expo = 25
set roll_rc_rate = 4
set pitch_rc_rate = 4
set yaw_rc_rate = 4
set roll_expo = 33
set pitch_expo = 33
set yaw_expo = 33
set roll_srate = 80
set pitch_srate = 80
set yaw_srate = 80

rateprofile 1

# rateprofile 1
set rateprofile_name = Z' Buttr
set thr_expo = 33
set roll_rc_rate = 6
set pitch_rc_rate = 6
set yaw_rc_rate = 6
set roll_expo = 42
set pitch_expo = 42
set yaw_expo = 42
set roll_srate = 74
set pitch_srate = 74
set yaw_srate = 74

rateprofile 2

# rateprofile 2
set rateprofile_name = Z's OG
set roll_rc_rate = 17
set pitch_rc_rate = 17
set yaw_rc_rate = 17
set roll_expo = 58
set pitch_expo = 58
set yaw_expo = 58
set roll_srate = 74
set pitch_srate = 74
set yaw_srate = 74

rateprofile 3

# rateprofile 3
set rateprofile_name = KittFPV
set thr_expo = 33
set roll_rc_rate = 20
set pitch_rc_rate = 20
set yaw_rc_rate = 17
set roll_expo = 42
set pitch_expo = 42
set yaw_expo = 31
set roll_srate = 62
set pitch_srate = 62

# restore original rateprofile selection
rateprofile 0

# save configuration
save
#

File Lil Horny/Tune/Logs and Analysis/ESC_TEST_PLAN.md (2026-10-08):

# AM32 switching-speed test (Alka's plan)

Goal: faster 3D direction switching on the Lucid AIO (AM32 2.21) via **Minimum Duty Cycle** and the **Motor KV** slider.
Betaflight stays on `whoop3d_master.txt` for every log, with **no CLI changes during this test**, so the ESC is the only variable.

## What the existing logs already show
Plot: `reports/esc_compare_history.png`

| Run | Firmware / setting | Switch time (to 100k eRPM in new direction), median | p90 |
|---|---|---|---|
| Pass 1 | factory AM32 (2.03) | **136 ms** | 169 |
| Pass 3 | 2.21, 15° | 146 ms | 175 |
| Pass 5 | 2.21, startup power 120 | 144 ms | 162 |
| Pass 6 | 2.21, startup power 100 | 148 ms | 177 |

On 2.21 the motors sit in a rough **30–60k eRPM range for ~80 ms** after the switch before climbing.
On the factory firmware they dip cleanly through zero at ~60 ms and climb straight out.
This matches Alka: 2.03 had a higher min duty, and the KV slider caps throttle at low rpm.
(Caveat: different days and props, and my stick technique varies; the A/B/C logs below fix that.)

## Steps (same props, full packs, similar flying with LOTS of throttle reversals)

Before each step: in the Multi ESC Config Tool, set **all four ESCs (M1–M4)** the same, click **Save Settings**,
then **Save Config File** with the step name. Bench test props off: flick through center 10+ times.
Any stutter, twitch, or a motor that doesn't restart means stop, back off a step, and report it.

| Step | Change | Config file name | Log name |
|---|---|---|---|
| **A: default** | Current settings (timing 15, startup 100, KV 10220, min duty default). Pass 6 counts as A if props haven't changed | `am32_A_default` | `ESC A default.BBL` |
| **B: min duty** | **Minimum Duty Cycle → 3** (Alka: 3 or 4) | `am32_B_minduty3` | `ESC B minduty3.BBL` |
| **C: + low KV** | Keep min duty 3, **Motor KV 10220 → ~5100** (half) | `am32_C_minduty3_kv5100` | `ESC C kv5100.BBL` |
| D (optional) | Alka's tip: higher min duty (4) **with lower startup power** (e.g. 80) for a strong but smooth start | `am32_D_...` | `ESC D ....BBL` |

**Finding the setting:** Multi ESC Config Tool 1.86 (per the screenshot) doesn't show Minimum Duty Cycle.
Check for a newer version of the tool or esc-configurator.com. If neither exposes it for 2.21, ask Alka where it lives.

After each flight: feel the motors (more low-rpm power = more heat), and note the feel at center stick.

## Analyze

```
.\.venv\Scripts\python.exe tools\esc_compare.py reports\esc_test.png "A default=ESC A default.BBL" "B minduty3=ESC B minduty3.BBL" "C kv5100=ESC C kv5100.BBL"
```
(set `$env:PYTHONPATH="C:\Users\Admin\Documents\Tuning\orangebox-0.5.0;tools"` first; trim crashes with `@0-55`)

Columns: `stop` / `restart` / `total` switch times (ms, lower = faster), `spread` between motors, `slow>200` count,
`err pk` attitude kick during the switch, `lowRPM rough` (eRPM ripple below 150k, the "rough transition" feel),
`low-thr wob` (wobble at <20% output).

## Results so far (2026-10-08)
Plot: `reports/esc_test_A_vs_B.png`. A = Pass 7 (2 packs, impact at 70 s trimmed), B = Pass 8 log 3 (impact at 79 s trimmed).

| | A default (P7, n=36) | **B min duty 3 (P8, n=23)** |
|---|---|---|
| Switch time median / p90 | 155 / 193 ms | **147 / 172 ms** |
| Slow switches (>200 ms) | 14 of 36 (39%) | **1 of 23 (4%)** |
| Motor spread | 73 ms | **49 ms** |
| Low-rpm roughness (eRPM ripple) | 3.5k | **1.8k (halved)** |
| Low-throttle wobble | 2.8 | 2.4 |
| Idle eRPM | 68k | **92k (+35%)** |
| Attitude kick during switch median / p90 | 74 / 147 | 85 / 173 (slightly worse) |

- Min duty **adds on top of** the Betaflight idle command (idle rpm +35% at the same `dshot_idle_value`).
- Much more consistent and smoother at low rpm, only ~8 ms faster on median.
- The ~40–110 ms rough 30–60k eRPM plateau after each switch is **unchanged**, so it isn't min duty.
  It looks like the low-rpm throttle limit, which is what step C (KV ~5100) targets.
- Slightly bigger attitude kick during switches is possibly the bigger thrust jump from +idle to −idle. Watch it in C.

### Step C added (Pass 9, impact at 88.6 s trimmed; pilot: "felt good in the air")
Plot: `reports/esc_test_ABC.png`. A now pools P6 + P7 (52 reversals).

| | A default | B min duty 3 | **C min duty 3 + KV 5100** |
|---|---|---|---|
| Switch time median / p90 | 153 / 183 ms | 147 / 172 | **142 / 172** |
| Restart phase (zero → 100k eRPM) | 45 ms | 42 | **39** |
| Slow switches (>200 ms) | 17 of 52 (33%) | 1 of 23 | **1 of 28 (4%)** |
| Motor spread | 70 ms | 49 | **45** |
| Per-motor median m0..m3 | 152 147 156 155 | 143 149 146 154 | **139 135 139 149** |
| Low-rpm roughness | 3.3k | **1.8k** | 3.5k |
| Attitude kick median / p90 | 60 / 136 | 85 / 173 | 68 / 172 |

- C is the fastest and most consistent 2.21 setup: −11 ms median, every motor faster, slow switches 33% → 4%.
  Still ~6 ms behind factory 2.03 (136 ms in Pass 1).
- Lower KV brought the low-rpm roughness back (B's smoothness gain gone).
- **The rough 30–60k eRPM window from ~40–110 ms after each switch is identical in A, B and C.**
  Neither setting moves it, so it's likely 2.21's reversal routine or telemetry not resolving low rpm. Factory 2.03
  (Pass 1) instead dips cleanly to ~10k at 60 ms. Question for Alka.
- Flight quality in C: pitch D-term and motor jitter slightly up (jitter 17 vs 14 in P6); could be the
  harder flying / prop wear. Watch it.
- Idle rpm at the idle command: A ~70–79k, B ~87–93k, C ~78–92k (rough in-flight measure).

### Step D: min duty 4 + KV 2100 (Pass 10; Alka suggested ~2200). Clean 86 s flight
Plot: `reports/esc_test_ABCD.png`

| | A | C | **D** |
|---|---|---|---|
| Switch median / p90 | 153 / 183 | 142 / 172 | **126 / 154 ms** |
| Per-motor m0..m3 | 152 147 156 155 | 139 135 139 149 | **125 128 126 130** |
| Motor spread | 70 | 45 | **38 ms** |
| Low-rpm roughness | 3.3k | 3.5k | **1.7k** |
| Slow >200 ms | 33% | 4% | 7% (2 of 30) |

- Fastest and smoothest config. Beats factory 2.03 (136 ms). The 30–60k plateau finally shrank (climbing by ~85 ms vs ~110).
- Side effect: pitch step overshoot 1.22 → 1.37 and steady error up slightly (roll/pitch 9.1/8.9 vs ~8 in C).
  More low-rpm authority from the ESC likely raises loop gain at low throttle. Betaflight candidate: `thrust_linear` 20 → 10.

### Step E: min duty 3 + KV 2100 (Pass 11, Alka's final recommendation). FINAL
Plot: `reports/esc_test_ABCDE.png`

| | D (duty 4) | **E (duty 3)** |
|---|---|---|
| Switch median / p90 | 126 / 154 | **126 / 148 ms** |
| Per-motor | 125 128 126 130 | 118 128 123 129 |
| Motor spread / slow | 38 / 2 | **34 / 1** |
| Low-rpm roughness | 1.7k | 1.8k |
| Pitch step peak | 1.37 | **1.22** |
| Inverted jitter | 19.2 | **16.6** |
| Reversal kick p90 | **149** | 185 |

D and E are near-identical; the pilot couldn't tell them apart either. Keeping E: same speed, slightly more consistent,
less pitch overshoot, and lower min duty = more desync margin (per Alka).

## Betaflight interaction to watch
Min duty puts a floor *under* Betaflight's `dshot_idle_value = 400` (4%): the lowest DShot value becomes ~3% duty,
so Betaflight's 4% idle now lands higher. Expect more thrust / float at center stick. If B/C switch faster but center
feels floaty, the follow-up is lowering `dshot_idle_value` (e.g. 400 → 300) to put the true idle back where it was.
That's a separate pass after the ESC test.

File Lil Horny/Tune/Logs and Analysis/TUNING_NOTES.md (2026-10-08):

# 3D Whoop Tuning Notes

**Craft:** 31mm props · 0802 16000kv · TBS Lucid AIO (AM32 ESC) · DJI O4 Lite · 2S 300mAh · ~30 g
**Firmware:** Betaflight 4.5.1 (AT32F435), 8k gyro / 8k PID, DShot600 bidirectional, 3D feature ON

## Pass 1 baseline: what the log showed (86 s, 24 reversals)

| Finding | Evidence | Fix in Pass 2 |
|---|---|---|
| **Wrong motor pole count** | Gyro noise line matches 12 poles (164× floor) vs 14 (1.8×) | `motor_poles = 12` |
| Reversals are slow and uneven | ~111 ms to get back to 60% rpm; motors differ by ~50 ms | idle 4%, thrust_linear, AM32 settings |
| Front motors (m1/m3) slowest | Slowest motor in 19 of 24 reversals; they run higher rpm (O4 Lite weight up front) | AM32 braking/startup, idle |
| PID fights the reversal | Motors pinned 2047 vs idle for 150 ms, then overshoot (peak error 48°/s median, 106 p90) | thrust_linear, idle |
| I-term zeroed 250 ms after every reversal | Hard-coded in Betaflight's 3D mixer, so it can't be changed in CLI | Stronger I/yaw so it recovers faster |
| Pitch overshoot | Step peak 1.34 with ~14 Hz ringing | f_pitch 105, d_min_pitch 38 |
| Roll FF overshoot then sag | Peak 1.14 → settles 0.88 | f_roll 110, i_roll 88 |
| Yaw under-holds | Settles at 0.82 of setpoint | p_yaw 50, i_yaw 95 |
| Big voltage sag | 7.86 V → 6.26 V | None. Pilot wants to feel the pack fade as the land cue, so vbat_sag_compensation stays 0 |
| Reverse thrust weaker at low end | At 20% command: 148k fwd vs 121k rev eRPM | (prop physics, so this is for awareness) |

Filters were left unchanged in Pass 2 so the pole fix can be measured on its own. Once the RPM filter is
tracking correctly, Pass 3 can probably open up the gyro/D-term lowpass for less delay.

## Pass 2 results (5 logs: 1 = prop-loss crash, 2/3 = arm blips, 4 = stall crash, 5 = good flight, truncated by full flash)

| Metric (log 5 vs Pass 1) | Pass 1 | Pass 2 |
|---|---|---|
| Steady tracking error roll / pitch / yaw (°/s RMS) | 14.9 / 13.9 / 9.2 | **9.0 / 6.3 / 2.9** |
| Filtered gyro 400–1000 Hz | -26 dB | **-31 dB** (RPM filter now on target) |
| D-term 400–1000 Hz | -21 dB | **-32 dB** |
| Reversal spin-up to 60% rpm (median) | 111 ms | 114 ms (logs 1/4: 122–150 ms) |
| Motor spread at reversal | 51 ms | **77 ms (worse)** |
| Reversal peak error median / p90 | 48 / 106 | **72 / 291 (worse)** |

- **Log 1 crash = prop loss on motor 2 (rear-left):** commanded full, rpm shot to 700k (normal max ~450k), so it was spinning with no load.
- **Log 4 crash = motor 0 (rear-right) failed to restart after a reversal:** 0 rpm while commanded full for 750 ms.
  Motor 0 is also the slowest reverser in log 5. Check that motor (hair/grit, bent shaft, crash damage).
- Reversals got worse while AM32 firmware + ESC settings changed in the same pass as the CLI. Cause found:
  the AM32 2.21 update reset **timing from 15° to 22.5°**. Pass 3 flies with it set back to 15°.
  (Sine startup was already OFF; AM32 settings as of Pass 3: timing 15, comp PWM, variable PWM,
  bidirectional, stuck rotor ON, startup power 100, poles 12, running brake 10.)
- **Roll flutter 10–16 Hz** is new in Pass 2. It grows with throttle and is stronger inverted, and the frequency
  shifts between packs. That fits a loose battery, not a PID gain problem. Fix the mount before touching PIDs.

## Pass 3 results (94 s, one clean flight, battery mount fixed, AM32 timing back to 15°)

| Metric | Pass 1 | Pass 2 (log 5) | Pass 3 |
|---|---|---|---|
| Steady tracking error roll / pitch / yaw (°/s RMS) | 14.9 / 13.9 / 9.2 | 9.0 / 6.3 / 2.9 | **7.7** / 6.6 / 3.0 |
| Motor spread at reversal | 51 ms | 77 ms | **52 ms** |
| Reversal peak error median / p90 | 48 / 106 | 72 / 291 | **54 / 135** |
| Reversal spin-up to 60% rpm | 111 ms | 114 ms | 115 ms (ESC-limited) |
| Step peak roll / pitch | 1.14 / 1.34 | 1.13 / 1.38 | **1.08 / 1.22** |

- Timing 15° fixed the Pass 2 reversal regression; no stalls.
- Remaining "propwash" = **12–15 Hz roll/pitch wobble that grows with throttle** (also present in Pass 1).
  TPA (D cut 65% at full throttle) is the prime suspect. Pass 4: tpa_rate 45 at 1450, d_min_roll 34.
- Low reverse throttle (inverted near center): pitch error ~13 °/s, mostly slow drift not wobble, so it's
  authority / I-term after the hard-coded 250 ms reset. Possible next levers: thrust_linear, anti_gravity.
- Next ESC-only experiment once Pass 4 is settled: AM32 startup power 100 → 120 for faster reversal spin-up.

## Pass 4 results (49 s; crash at 47.8 s was an impact, 9.4 g, motors healthy, trimmed off)

| Wobble 8–60 Hz, roll (upright) | 10–20% | 35–60% | 60–100% |
|---|---|---|---|
| Pass 3 | 7.2 | 5.0 | 8.4 |
| **Pass 4** | **2.3** | **3.5** | **5.8** |

- TPA 45 @ 1450 + d_min_roll 34 cut upright wobble 30–70%. Steady pitch error best yet (5.5).
- Roll step response clean: 1.12 peak, settles at 1.0.
- Cost: D-term noise +50% (80–500 Hz), motor-command jitter 10 → 14 upright, **17 inverted**.
  Inverted is the noisiest state (reverse flow through the ducts is turbulent). Watch motor temps.
- Inverted wobble did not improve (35–60%: 4.5 → 5.7, short sample of 9 s).
- Pitch still overshoots (1.55, only 20 windows). Pass 5: p_pitch 44, f_pitch 95.
- ESC test in Pass 5: AM32 startup power 100 → 120 (reversal spin-up stuck at ~112 ms).
- Pilot report after Pass 4: motor temps fine, so there's still room for D despite the extra noise.

## Pass 5 results (66 s; tree hit at 55.8 s, 7.1 g, recovered, motors fine; analyzed 0–55.5 s)

| Metric | Pass 3 | Pass 4 | Pass 5 |
|---|---|---|---|
| Steady error roll / pitch / yaw | 7.7 / 6.6 / 3.0 | 7.7 / 5.5 / 2.8 | **6.3** / 6.5 / **2.6** |
| Step peak roll / pitch / yaw | 1.08 / 1.22 / 0.86 | 1.12 / 1.55 / 0.85 | **1.03 / 1.35 / 0.92** |
| Pitch t50 (speed) | 11 ms | 11 ms | 17 ms (slower) |
| Reversal spin-up / motor spread | 115 / 52 ms | 112 / 47 ms | 122 / 70 ms (worse) |
| Motor jitter upright / inverted | 10 / 10 | 14 / 17 | 16 / 24 |

- AM32 startup power 120 didn't help reversals, so revert to 100.
- Worst reversal (43.2 s) = 800°/s roll with throttle lingering at center: direction flipped twice in
  140 ms and props were near 0 rpm for ~300 ms. That's physics/technique, not tune.
- **Effective 3D deadband is ±3 µs** (switches at 1497 / 1503 every pass). Almost no dead zone, which is crisp,
  but the slightest dither at center flips direction. Only 1 chatter event in 4 flights, so left as is.
  Raising `3d_deadband_throttle` to ~10–15 would stop it at the cost of a small dead spot.
- Raw gyro noise inverted rising each pass, so likely worn/damaged props. Fresh props for Pass 6.
- Pass 6: d_min_pitch 42, f_pitch 100.

## Pass 6 results: MASTER TUNE (106 s clean flight, fresh props, startup power back to 100)

| Metric | Pass 1 | Pass 6 | Change |
|---|---|---|---|
| Steady error roll / pitch / yaw (°/s) | 14.9 / 13.9 / 9.2 | 7.5 / 6.1 / 2.9 | −50% / −56% / −68% |
| Step peak roll / pitch | 1.14 / 1.34 | **1.00 / 1.13** | overshoot gone / mostly gone |
| Reversal peak error median / p90 | 48 / 106 | **37 / 84** | best of all passes |
| Inverted motor jitter | (Pass 5: 24) | 16 | fresh props fixed it |
| Reversal spin-up | 111 ms | 127 ms | ESC/motor limit, ~110–127 every pass |

Full config: `whoop3d_master.txt`. Remaining ideas, only if something bugs you in flight:
- Yaw tracks at ~0.8 of setpoint in every pass regardless of P/I. Steady yaw error is tiny, so only chase it if yaw feels loose.
- `3d_deadband_throttle` (currently ±3 µs) if center-stick direction flips ever annoy you.
- Fresh props after crashes. Pass 5→6 showed worn props alone raised inverted noise 50%.

## Pass 11 tic-tock wobble → Pass 12 (2026-10-08)

Tic-tocks at 54–58 s and 62–69 s: wobble bursts sit in the ~0.5 s after **every** direction switch
(props spinning back up into the quad's own wash), calm during the steady full-throttle swings.
`tools/post_reversal.py`, wobble r/p (°/s) by time since switch:

| Log | 0–130 ms | 130–250 ms | 250–500 ms | calm |
|---|---|---|---|---|
| Pass 1 | 5.3 / 5.0 | 13.5 / 9.3 | 13.1 / 8.3 | 5.5 / 4.9 |
| Pass 6 | 3.4 / 3.3 | 9.9 / 5.9 | 11.2 / 8.9 | 4.0 / 2.8 |
| Pass 11 | 7.9 / 6.2 | 18.1 / 12.3 | 17.7 / 11.5 | 3.9 / 3.2 |

- Present in every pass (not caused by the AM32 change). ~12 Hz. Throttle there is 22–46%, below the TPA
  breakpoint, so TPA isn't cutting D. The 130–250 ms window is also when Betaflight holds I-term at zero (hard-coded).
- Roll is ~50% worse than pitch and has less D. Pass 13: d_min_roll 34→38, d_roll 40→44 (matching pitch).
- Pass 12 (flown first, pilot's choice): dshot_idle_value 400 → 200. AM32 min duty 3 adds on top of BF idle
  (effective ~7% now), so 2% puts it back near ~5%. Watch center float, center-crossing smoothness, and the 0–130 ms wobble.
- Expect a reduction, not elimination; some of this is the physics of flying through your own wash.

## Pass 12 results: idle 4% → 2% (67 s; branch hit at 40.9 s and odd last 2 s trimmed: `@0-39.5+@41.5-64.5`)

| | Pass 11 (idle 4%) | **Pass 12 (idle 2%)** |
|---|---|---|
| Idle eRPM upright / inverted | 82k / 108k | **79k / 79k** (back to pre-ESC-test level) |
| Switch time median / p90 | 126 / 148 ms | 126 / 160 ms |
| Stop / restart phase | 84 / 36 ms | 76 / 43 ms |
| Attitude kick during switch, median / p90 | 84 / 185 | **48 / 161** |
| Post-switch wobble 0–130 / 130–250 / 250–500 ms (roll) | 7.9 / 18.1 / 17.7 | 7.0 / **20.7** / 16.3 |
| Same, pitch | 6.2 / 12.3 / 11.5 | **4.8 / 11.0 / 8.0** |
| Steady error r / p / y | 9.3 / 8.2 / 3.8 | **7.9 / 7.1 / 3.6** |
| Step peak roll / pitch | 1.06 / 1.22 | 1.04 / 1.20 |

- Keep 2%: same switch speed, center crossings ~40% smoother, inverted idle no longer higher than upright.
- Remaining hot spot: roll 130–250 ms after a switch (20.7). That's the target of Pass 13 (roll D 38/44).

## Pass 13 results: roll D 38/44 (98 s; crash at 97.55 s = collision while inverted, tracking clean right before)

| Roll wobble after a switch (°/s) | 0–130 | 130–250 | 250–500 | 500–1000 ms |
|---|---|---|---|---|
| Pass 12 | 7.0 | 20.7 | 16.3 | 9.7 |
| **Pass 13** | **6.0** | 20.9 | **13.6** | **8.3** |

- Attitude kick during switches: median 43, p90 108, the best of any pass (Pass 12: 48 / 158).
- Pilot: "feels better". Kept, and the master is updated.
- The 130–250 ms roll peak did not move with more D. That window = Betaflight's hard-coded I-term hold +
  motors finishing their restart at different times (35–42 ms spread); roll has less inertia than pitch so it shows more.
  Likely the floor for this hardware/firmware combination.
- Cost: roll D-term 20–80 Hz +48% upright, motor jitter 15 → 18 upright, 20 → 24 inverted.
  Pilot report after Pass 13: motor temps fine.
- Pass 14 (optional): thrust_linear 20 → 10, since the ESC now provides the low-end boost.

## Pass 14 results: thrust_linear 10 (128 s, no impacts; flash filled up). KEPT, master updated

| Wobble after a switch, roll / pitch (°/s) | 0–130 | 130–250 | 250–500 | 500–1000 ms |
|---|---|---|---|---|
| Pass 13 (TL 20) | 6.0 / 4.6 | 20.9 / 11.1 | 13.6 / 10.1 | 8.3 / 6.3 |
| **Pass 14 (TL 10)** | 7.0 / 5.5 | **9.1 / 6.5** | **10.4 / 7.5** | 8.6 / 7.1 |

- The 130–250 ms peak D couldn't touch dropped 56%: the ESC and thrust_linear were both boosting the restart.
- Low-rpm eRPM ripple 2.1k → 1.2k (smoothest yet); inverted motor jitter 24 → 17; switch kick p90 108 → 82 (best).
- Switch time unchanged (125 ms).
- Cost: inverted near center (REV 10–35% output) pitch tracking a bit looser (full-band 9–13 → 12–17 °/s), over ~3 s of flight.
- Roll step peak 1.04 → 0.93 (slightly soft). Optional Pass 15: f_roll 110 → 120.
- Remaining reversal flutters: (1) reversing mid-flip, where the front motors pin at the new-direction idle and pitch
  overshoots (3D mixer limit); (2) impossible eRPM jumps 60–140 ms after switches (`tools/erpm_glitch.py`):
  present on AM32 2.21 at every setting (~0.1–0.8 per reversal), ~none on factory 2.03, mostly motor 0 (ESC M1, the
  motor that stalled in Pass 2). Either 2.21 restart telemetry or brief desyncs. Worth sending to Alka, and check motor 0.

## AM32 ESC settings (esc-configurator.com, Chrome, battery plugged in, props off)

Read the settings first and **screenshot them as a backup**. All 4 ESCs should match.

| Setting | Recommend | Why |
|---|---|---|
| Bidirectional / 3D | **ON** | Required for 3D (already on, since it flies) |
| Motor poles | **12** | Matches the motors |
| Complementary PWM | **ON** | Active braking lets the prop stop faster before it reverses |
| Sinusoidal startup | **OFF** (keep) | Sine range is 15% but idle is 4%, so with it ON every reversal would run in slow open-loop sine mode |
| Low RPM power protect | not shown in Multi ESC Config Tool 1.86 | |
| Stuck rotor protection | ON for now | Possible reason motor 0 never retried in the log 4 stall. Revisit only if stalls repeat at 15° timing |
| Stall protection | OFF | Meant for crawlers |
| Startup power | **100** | 120 tested in Pass 5: reversals got slower/less even. Keep 100 |
| Timing advance | **15°** | AM32 2.21 update silently reset it to 22.5°, and Pass 2 flew at 22.5°. Prime suspect for the slower reversals and the motor 0 restart failure |
| Motor KV | 10220 (field max) | Real motors are 16000kv but AM32 can't store more than 10220; leave it at max |
| Running brake level | 10 (max) | Good: strongest braking on decel = faster stop before reversal |
| PWM frequency | leave, or try 48 kHz | Smoother/quieter on tiny motors, small efficiency cost |

**Updating AM32:** in esc-configurator, flash the latest **stable** release for the *exact same target name*
the ESC reports now (Lucid AIO = AT32F421). Flashing can reset settings, so re-apply the table above.
Change ESC things in a **separate flight** from CLI changes so we can tell what helped.

## Test procedure per pass
1. Paste the CLI file, `save`, and check the motors tab (props off) that all 4 spin correctly both directions.
2. Fly a full pack with a mix of: slow center crossings, fast flips through center, inverted hover, punch-outs.
3. Drop the .BBL in this folder and run `.\analyze.ps1 "Pass 2 Full Flight.BBL" "Pass 2"`.
4. Compare rows in `reports/scorecard.csv`. Key numbers: `rev_spinup_ms_med`, `rev_motor_spread_ms_med`,
   `rev_peak_err_med/p90`, `step_peak_*`, `gyro_unfilt_400_1000_db_roll`.
5. Feel and motor temps matter as much as the numbers. Note both.

## Tools (`tools/`)
- `bbl_load.py`: decodes .BBL to numpy (cached .npz)
- `bbl_headers.py`: dumps every config value in the log
- `poles_check.py`: verifies motor_poles from gyro noise vs eRPM
- `reversals.py`: per-reversal motor stop/spin-up timing, motor spread, attitude error, plot of the worst events
- `noise_step.py`: gyro/D-term spectra, filter attenuation, step response, command→rpm by direction
- `scorecard.py`: one-row summary appended to `reports/scorecard.csv`
- `list_logs.py`: lists every log inside a multi-log .BBL (any tool accepts `"file.BBL#N"`)
- `crash.py`: last seconds before a crash, flags prop loss (rpm too high) vs stall (rpm 0 at high command)
- `flutter.py` / `flutter_vs_throttle.py`: 2–60 Hz flutter peaks, and where in the throttle range they live
- `propwash.py`: wobble after throttle chops, and tracking error by motor-output band split upright vs inverted
- `direction_noise.py`: upright vs inverted gyro/D-term noise and motor jitter at the same motor output
- `esc_compare.py`: ESC A/B comparison of switch time (stop / restart / total), motor spread, low-rpm roughness,
  with an overlay plot of median eRPM through reversals (see `ESC_TEST_PLAN.md`)
- `post_reversal.py`: wobble vs time since each direction switch (tic-tocks / post-reversal propwash)
- `ticktock.py`, `timeline.py`, `plot_window.py`: find hard 3D maneuvers, per-second overview, scope plot of a window
- `deadband.py`: actual 3D center deadband from where direction switches, plus chatter count
- `window.py`: quick table of throttle/motors/rpm/gyro over a time range (`window.py file 43.0 43.8`)
- Any tool accepts `"file.BBL@0-47.6"` to trim (e.g. cut a crash off the end)

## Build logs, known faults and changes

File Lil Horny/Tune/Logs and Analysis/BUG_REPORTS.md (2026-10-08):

# Bug report drafts: motors spin to full throttle on save/disconnect (3D mode)

Fill in the `[brackets]` before posting. Post the Betaflight one first, then link it from the AM32 one (and vice versa).

- Betaflight Configurator issues: https://github.com/betaflight/betaflight-configurator/issues
- AM32 issues: https://github.com/am32-firmware/AM32/issues

---

## 1. Betaflight (Configurator / firmware)

**Title:** 3D mode + bidirectional DShot: motors run up to full throttle on CLI `save` / Configurator disconnect while battery connected

**Description**
With `feature 3D` enabled and DShot600 bidirectional, all motors spin up to full throttle when I save settings or disconnect Configurator with a battery plugged in. It only happens while connected to Configurator over USB. Normal arming, disarming, flight and power cycling all behave correctly.

**Steps to reproduce**
1. Enable 3D (`feature 3D`), DShot600 with `dshot_bidir = ON`, ESCs (AM32) in bidirectional mode.
2. Connect battery + USB, open Configurator.
3. Run `save` in the CLI **or** click Disconnect: [which one(s)]
4. Motors spin up to full throttle [forward/reverse?] and [stop by themselves after ~X s / keep running until the battery is unplugged].

**Expected:** motors stay stopped (3D neutral) through save/reboot and disconnect.

**Environment**
- Firmware: Betaflight 4.5.1 (77d01ba3b), AT32F435M, target TBS_LUCID_AIO
- Configurator version: [x.y.z]
- Motor protocol: DShot600, bidirectional, 8k/8k, `dshot_idle_value = 400`, `motor_poles = 12`
- 3D settings: [paste `get 3d` output]
- ESC: on-board AM32 [version], bidirectional mode ON
- Receiver: CRSF

**Attachments:** `diff all`, a short phone video of it happening (props off).

---

## 2. AM32

**Title:** Bidirectional mode: motors go to full throttle when FC reboots / Configurator disconnects (TBS Lucid AIO)

**Description**
In bidirectional (3D) mode, the motors run up to full throttle when the flight controller reboots after a Betaflight `save`, or when Betaflight Configurator disconnects. The battery is connected and the props are off. The ESC behaves correctly when armed/disarmed normally and on power cycle. My guess is that the ESC misreads the signal line during the FC reboot or the Configurator stop command (e.g. treating it as a PWM/servo input or a non-neutral 3D value). I haven't confirmed that.

**Steps to reproduce**
1. AM32 [version] on TBS Lucid AIO ESC (target: [target name shown in esc-configurator]), bidirectional ON, motor poles 12.
2. Betaflight 4.5.1, 3D feature, DShot600 bidirectional.
3. Battery + USB connected, then `save` in the Betaflight CLI / Disconnect in Configurator.
4. Motors spin to full throttle [direction], [duration / until battery removed].

**Notes**
- [Did this happen on the previous AM32 version? yes / no / not tested]
- ESC settings: [screenshot from esc-configurator]
- Linked Betaflight issue: [link]

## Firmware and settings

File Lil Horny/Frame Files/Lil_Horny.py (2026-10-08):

"""Lil' Horny - Fusion 360 mock-up script.

Fractal 65 Lite frame (slimmed) + DJI O4 Lite + TBS Lucid AIO 1-2S + 0802 motors + batteries,
for designing the O4 camera / battery / antenna-horn mount.

All dimensions are millimetres and live in the CONFIG block. Edit them and re-run to regenerate.
Frame +Y = front, +X = right, +Z = up.

The frame is rebuilt from a photo of the real plate and then streamlined. It is made of editable
sketches inside the "Frame" component:
  "Frame bars+pads"   overlapping bar/pad shapes; extruded to the plate (only material regions)
  "Frame holes"       circles; cut through the plate
Real STEP models of the O4 Lite and the Lucid (next to this script) are imported and auto-placed.
Values marked (ASSUMED) are estimates: verify with calipers.
"""
import math
import os
import traceback

import adsk.core
import adsk.fusion

PROJECT = "Lil' Horny"

# ----------------------------- CONFIG (mm) -----------------------------
MOTOR_X = 26.0            # half left-right motor spacing (ASSUMED: ~65 mm diagonal, squished X)
MOTOR_Y = 19.5            # half front-back motor spacing (ASSUMED)
PLATE_T = 1.5             # carbon plate thickness (spec)
BAR_W = 2.0               # bar width: slimmed 1 mm from the stock ~3 mm for airflow
CENTER_CROSS = False      # stock frame has a + cross between the bosses; off for airflow
BOSS_D = 5.0              # screw boss diameter around AIO holes
AIO_PATTERN = 25.5        # AIO/O4 hole pattern side (spec). Real frame has it turned 45 deg (diamond)
AIO_HOLE_D = 2.2          # M2 clearance
STACK_YAW = 45.0          # boards turned 45 deg to match the frame's diamond hole layout

MOTOR_HOLE_D = 3.6        # centre hole in each motor pad
TRI_R, TRI_D = 3.0, 1.5   # tri-mount: 6.0 mm bolt circle, M1.4 clearance (frame also lists 5.5 mm / M1.6)
PAD_D = 8.4               # motor pad: stays inside the motor's 11 mm footprint
SCREW_BUMP_D = 3.2        # extra carbon around each motor screw hole (stays under the motor base arms)

# 0802 motor: 11 mm wide bell, 6 mm tall; 3 mm tall Y-shaped base whose arms only reach the screw holes
MOTOR_D = 11.0            # bell diameter (you measured 11 mm total width)
MOTOR_BELL_H = 6.0        # (you measured)
MOTOR_BASE_H = 3.0        # (you measured)
MOTOR_HUB_D = 5.0         # centre of the Y base (ASSUMED)
MOTOR_ARM_W = 2.2         # Y arm width (ASSUMED)
MOTOR_ARM_END_D = 2.8     # round end of each arm around the screw (ASSUMED)
MOTOR_SHAFT_D = 1.5
MOTOR_SHAFT_H = 1.5
PROP_D = 31.0             # 31 mm props
PROP_T = 0.5
PROP_Z = PLATE_T + MOTOR_BASE_H + MOTOR_BELL_H + 0.2   # just above the bell

# Printed TPU standoffs (two separate components so each set exports/prints on its own)
STANDOFF_OD = 4.0         # outside diameter
STANDOFF_ID = 2.2         # bore: M2 screw clearance
EXPORT_STL = True         # write each set (4 standoffs) as one STL into an "stl" folder next to this script

# Stack order (bottom -> top): frame plate, O4 Lite, Lucid AIO (micro-USB / motor-socket side up).
STACK_H = 8.0             # plate top -> Lucid PCB top (lowered 3 mm from 11; top standoffs 4.7 mm)

O4_STANDOFF = 1.5         # plate top -> O4 PCB bottom (clears O4 bottom parts)
O4_SIZE = 30.0            # transmission module 30 x 30 x 6 (DJI drawing)
O4_HOLE = 2.6             # 4 x 2.6 (DJI drawing; slotted to the corners, slot not modelled)
O4_PCB_T = 1.0            # (ASSUMED)
O4_COMP_SIZE = 18.0       # (ASSUMED) components split so total height = 6 mm
O4_COMP_TOP_H = 4.0
O4_COMP_BOT_H = 1.0

# TBS Lucid AIO 1-2S. Layout taken from TBS's own STEP (ECAD export): 0.8 mm PCB, 28 x 28 with
# ears to 30 x 30. In your build the side with the micro-USB, ESC FETs and the 4 Molex PicoBlade
# motor sockets faces UP; the MCU side (RX u.FL, buttons, inductor) faces down at the O4.
AIO_SIZE = 28.0
AIO_EAR_D = 4.5
AIO_HOLE = 3.0            # PCB hole for the supplied rubber grommets (ASSUMED)
AIO_PCB_T = 0.8           # (TBS STEP)
LUCID_USB_DIR = 90.0      # direction the micro-USB corner points, deg (0 = right, 90 = front,
                          # 270 = rear). Use 0/90/180/270 so the holes line up with the frame.
# Parts in the Lucid's own frame with the USB corner at +45 deg (USB side up):
# (name, x, y, rot deg, size along rot, size across, height, side) - positions from TBS STEP,
# sizes ASSUMED from the part numbers.
LUCID_PARTS = [
    ("Micro-USB (J5)", 9.72, 9.71, -45.0, 7.5, 5.0, 3.0, "up"),
    ("Motor socket J1", 14.03 - 1.7, -7.30, 90.0, 5.7, 3.3, 5.2, "up"),
    ("Motor socket J2", 7.30, -14.03 + 1.7, 0.0, 5.7, 3.3, 5.2, "up"),
    ("Motor socket J3", -7.30, 14.05 - 1.7, 0.0, 5.7, 3.3, 5.2, "up"),
    ("Motor socket J4", -14.03 + 1.7, 7.30, 90.0, 5.7, 3.3, 5.2, "up"),
    ("ESC FETs Q1A", 8.10, 3.03, 0.0, 3.3, 3.3, 0.9, "up"),
    ("ESC FETs Q1B", 3.00, -8.07, 0.0, 3.3, 3.3, 0.9, "up"),
    ("ESC FETs Q1C", -3.25, 8.43, 0.0, 3.3, 3.3, 0.9, "up"),
    ("ESC FETs Q1D", -8.43, -3.40, 0.0, 3.3, 3.3, 0.9, "up"),
    ("MCU / gyro / RX chips", 0.0, 0.0, 0.0, 16.0, 16.0, 1.0, "down"),
    ("Inductor L1", 9.11, 1.35, 0.0, 3.0, 3.0, 1.4, "down"),
    ("Button SW1", -10.95, 7.80, 0.0, 3.5, 2.9, 1.2, "down"),
    ("Button SW2", -12.80, 3.06, 0.0, 3.5, 2.9, 1.2, "down"),
    ("Crossfire RX u.FL (J6)", -7.80, -10.35, 0.0, 3.0, 3.0, 1.3, "down"),
]

# DJI O4 Lite camera, bare module (no DJI adapter). From DJI's dimension drawing:
CAM_DEPTH = 13.44               # lens tip -> back of rear connector (DJI)
CAM_LENS_D = 8.5                # (DJI)
CAM_LENS_L = 1.5                # lens proud of the body (DJI)
CAM_BODY_WH = 10.8              # square body / lens holder (DJI)
CAM_BODY_D = 5.2                # (DJI)
CAM_BODY_Z_OFF = -0.5           # body centre sits ~0.5 below board centre (scaled from DJI drawing)
CAM_PCB = (12.36, 3.3, 16.5)    # board stack W, thickness, H (W/H DJI; thickness scaled from drawing)
CAM_TOP_TAB = (13.10, 1.5)      # wider tabs along the top edge: width, height (DJI width)
CAM_CONN = (8.0, CAM_DEPTH - CAM_LENS_L - CAM_BODY_D - CAM_PCB[1], 4.5)  # rear connector at the TOP
CAM_CONN_TOP_GAP = 1.1          # connector starts this far below the board top (scaled)
CAM_REAR_PART = (6.0, 1.0, 4.0) # small part low on the back (scaled)
CAM_CABLE = (6.0, 1.0, 4.0)     # flex cable leaving the top: keep-out W, thickness, length up (ASSUMED)
CAM_REAR_Y = 22.0               # Y of the camera's rear face (connector back)
CAM_CENTER_Z = 9.0              # camera PCB centre height above plate bottom (ASSUMED)
CAM_TILT_DEG = 0.0              # lens-up tilt (0 = level), pivots about the camera's rear centre
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

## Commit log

2026-10-08 Add Lil Horny 3D whoop project
    Frame files, tune, AM32 ESC configs, and blackbox logs/analysis.
    [Antenna Mount.obj, Battery Mount.obj, Camera Mount.obj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]
2026-10-09 Remove 19000kv motor option (doesn't work)
2026-10-09 Use stock 2200 KV in ESC settings
2026-10-11 Update README.md
    Added a link to new preferred battery, and a link to the flight footage and vlog covering this project.
2026-10-29 Add BetaFlight 3D Edition: Lucid AIO firmware, pilot guide, tunes, source links
    New project folder BetaFlight3DEdition/ for pilots testing the 3D-mode Betaflight fork:
    - firmware/TBS_LUCID_AIO: v0.1.0-test hex (also on the betaflight fork release page)
    - TESTING_GUIDE.md: step-by-step flash, setup, bench check and 4-pack A/B test
    - tunes/: Lucid starter tune (3D/motor/filter/PID only) and ZoeFPV's full diff all
    updated to the Pass 30/31 tune
    - BUILD_FROM_SOURCE.md: source downloads and build steps
2026-10-29 BetaFlight 3D Edition: add CrazyBee F4 SX1280 build and board request form
    - firmware/CRAZYBEEF4SX1280: v0.1.0-test hex (same commit as the Lucid build)
    - tunes/3D_Edition_settings_CRAZYBEEF4SX1280.txt: 3D + test settings only
    - TESTING_GUIDE: CrazyBee section (BLHeli_S/Bluejay, bidirectional ESC, dshot_bidir)
    - README/guide/build docs: link the board build request form
2026-10-30 BetaFlight 3D Edition: firmware for 41 boards (BOARDS.md) and 2026.6.2 build for XRotor F7 Conv
2026-10-30 Docs: use am32.ca/configurator instead of esc-configurator.com
    Updates every reference in the BetaFlight 3D Edition guide, Lil Horny setup guide, tune notes,
    bug-report drafts, ESC test plan and the repo README.
2026-10-31 BetaFlight 3D Edition v0.2.2-test: 44 boards, simpler testing guide
    - v0.2.2 firmware for 44 boards, incl. requested DARWINF4SX1280HD,
    FLYWOOF722PROV2 and SEQUREH7V2
    - testing guide rewritten: Block A (stock) x2 packs, Block B
    (PER_DIRECTION, + RPM release with RPM telemetry) x2 packs
    - README settings reference for all v0.2.x settings, results so far
    - tune files carry Block A
2026-10-31 BetaFlight 3D Edition v0.3.0-test: anti-gravity gate, 3D dynamic idle, best settings
    - v0.3.0 firmware for 44 boards (commit 9421121f7)
    - README: new settings, best-settings block, results (one same-day A/B,
    indicative), restart sync tried and dropped
    - testing guide: Block B is now the recommended package (with / without
    RPM telemetry); Block A resets the new settings to stock
    - tunes: best settings file; starter tunes carry the new settings off
2026-11-02 v0.3.1 testing guide: fix bench tests 1-3 procedures
    - Test 1: raise vbat_warning_cell_voltage too (critical is only reached via warning); restore all three, sag comp depends on the warning voltage
    - Test 2: hold throttle off center at link loss, otherwise failsafe_throttle_low_delay skips stage 2; log check for phase LANDING
    - Test 3: thr_mid 25 (45 moves center only 2% with thr_expo 25; no effect without expo)
    - 3D mode switch must be off; log-based pass criteria
2026-11-04 BetaFlight 3D Edition v0.3.1-test: stable main version, best settings as defaults
    - README/BOARDS/TESTING_GUIDE/BUILD_FROM_SOURCE: v0.3.1-test (161e867a9), 44 boards, new SHA-256
    - V0.3.1_FEATURE_TESTING.md: per-feature test status and bench/flight tests (fixes 1-4 not hardware-tested yet)
    - EXPERIMENTAL_v0.3.1_TESTING.md: now a pointer (experimental branch removed)
    - tunes: best settings v0.3.1; firmware copies updated
2026-11-04 BetaFlight 3D Edition: wording fixes (sag comp isn't a reverse-thrust bug, A/B caveat, board list label)
2026-11-04 BetaFlight 3D Edition: 41 more boards (88 total), incl. Fractal Engineering SP8 AM32 AIO
    Common AIOs (many with 32-bit/AM32 ESCs) and popular 5-inch FCs from the official 4.5 targets; FRACSP8AIO from
    Fractal's own target definition (targets/FRACSP8AIO, adapted for 4.5).
2026-11-04 BlueJay3D v0.22.0-3D: publish 8-bit 3D ESC firmware, 135 targets, configurator, presets & testing guide
2026-11-04 BetaFlight 3D Edition: add TMOTORF7 (89 boards)
2026-11-04 BetaFlight 3D Edition: note TMOTORF7 stack ESC (AM32 TMOTOR_G071)
2026-11-05 BlueJay3D Configurator: Add 1-click local launcher, disconnect button & guide
2026-11-05 BetaFlight 3D Edition v0.3.2-test: Betaflight 2026.6.2 base, 90 boards (JHEF745V2 added)
    - README/BOARDS/TESTING_GUIDE/feature notes/BUILD_FROM_SOURCE: v0.3.2-test (ea347bdd5), not flown yet; v0.3.1 kept as the 4.5 fallback
    - new 3D fix: autopilot (altitude hold incl. failsafe landing, GPS rescue) runs the motors upright
    - 2026.6 renames explained (D-max, motor_idle); ARGUSF7AIO -> AXISFLYINGF7AIO upstream rename
    - FRACSP8AIO target per version; firmware copies updated
2026-11-09 BlueJay3D: source-check the board-to-target lookup table
    Every quick-lookup row now cites the manufacturer/retailer listing or the
    Bluejay Tested Hardware wiki for the factory ESC layout. Removed the
    "or <other layout>" alternatives: different layout letters are wired
    differently and lower deadtimes risk shoot-through.
    Corrected rows that disagreed with their sources: X12 -> Z_H_30,
    CrazyF411 -> F_H_40, TAKER F411 -> G_H_30 (12A-E -> C_X_30), DarwinFPV
    F411 15A -> S_H_50, SuperX -> O_H_5, BeeBrain BLV4 -> S_H_40, JHEMCU
    GHF411AIO-HD -> G_H_30, SpeedyBee F405 V3 BLS -> J_H_50, F405 Mini BLS ->
    J_H_40, SucceX-E V2 -> G_H_30, Zeus 4-in-1 -> F_H_40, Tinyhawk II ->
    S_H_90 (not built). Unverified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
2026-11-10 BetaFlight 3D Edition v0.3.3-test: frozen I-term and reverse airmode fixes, flown on 5-inch, 90 boards
    Docs, board list and build notes now point at v0.3.3 (fb947bea1). Adds the 5-inch 3D tune preset and
    Lil Horny's v0.3.3 CLI; v0.3.2 moves to older versions.
2026-11-10 BetaFlight 3D Edition: 5-inch 3D tune as a safe paste-in file
    Tune only (no board, ports, switches, motor order, features or rates), 3D settings and the 2026.6 defaults it depends on
    written out, wrapped in a command batch so any rejected line blocks the save. Rates are an optional commented block.
    Verified on the XRotor: built from defaults it reproduces the flown config with no differences.
2026-11-10 BetaFlight 3D Edition: documentation overhaul, 31 mm whoop preset
    - New HOW_IT_WORKS.md: every change from stock Betaflight, how it works, why, settings reference, evidence and limits
    - New PRESETS.md and a 31 mm whoop preset next to the 5-inch one; both featured at the top of the README
    - New CHANGELOG.md; README rewritten; FEATURE_TESTING.md (renamed); testing guide, board list and Lil Horny guides point at the presets
    - README checksums corrected to the v0.3.3 hexes
2026-11-10 BetaFlight 3D Edition docs: review fixes
    - Keep the old V0.3.1_FEATURE_TESTING.md link alive (redirect); the Lucid starter tune is labelled as stock-behaviour Block A
    - Presets no longer set min_check / max_check (radio endpoints); the 5-inch preset re-tested live (93 lines, zero differences)
    - Claims limited to what was tested: T-Motor hover-tested only, whoop preset not yet loaded live, settings kept only on the same
    Betaflight base, dynamic-idle comparison caveat
2026-11-10 BetaFlight 3D Edition docs: the whoop has flown on 2026.6 (v0.3.3), pilot report only
